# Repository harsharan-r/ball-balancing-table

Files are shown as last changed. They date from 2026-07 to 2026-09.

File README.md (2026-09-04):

# Ball Balancing Table 

A small deskstop ping pong ball balancing machine that uses a Pi Camera Module 3 to track the ping pong ball, and uses three MG 996R on a 3 DOF Stewart type platform. Everything is done via Raspberry Pi 3B+ 1 GB ram with a adafruit servo hat. The goal was to explore computer vision, state estimation, and motion controls. 

## Demo

## About this project

Three servo-actuated legs drive an RRS parallel linkage under a 120mm platform. A Pi Camera
tracks the ball's position via HSV color masking, a Kalman filter smooths that into a
position + velocity estimate, and independent PID loops on roll/pitch/height keep the ball
centered.

## Getting Started

### Prerequisites

- Raspberry Pi (tested on a Pi 3B+) running Raspberry Pi OS, with a Pi Camera Module and an
  Adafruit PCA9685 servo hat wired over I2C
- `cmake` >= 3.16, a C++17 compiler
- System packages: `opencv4`, `libcamera`, `yaml-cpp`, `pigpio`, `wiringPi`

### Installation

```
./balance setup   # installs system packages, enables I2C, configures the CMake build dir
./balance build   # cmake --build build
```

### Usage

```
./balance run
```

Runs `sudo ./build/main`, since GPIO/I2C access requires root. Use the two GPIO buttons to
move between idle / ready / calibration / running states (see `CLAUDE.md` for details).

`./balance` is a thin wrapper around `scripts/setup.sh`, `scripts/build.sh`, and
`scripts/run.sh`, which can also be run directly.

## Implementation Details

### Camera Pipeline

The camera pipeline uses libcamera to get images from pi camera module 3.

Each libcamera frame buffer is `mmap`'d directly into a `cv::Mat` header — zero copy, no
`.clone()` needed. From there the pipeline is ordered to shrink the image as early as
possible, before any of the more expensive per-pixel work runs:

1. **Crop to ROI, then downsample** — a plain `cv::Mat` sub-view followed
   by `cv::resize`. The image is first cropped to only cover the area of the platform, then resized to reduce its quality to a point where there are enough pixels (10+) to define the ping pong ball at a 50 cm distance. Cropping/resizing first means every later stage runs on a much smaller
   image instead of the full sensor resolution.
2. **BGRA → BGR → HSV** color conversion on the now-small frame.

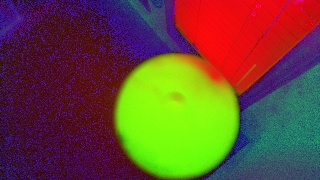
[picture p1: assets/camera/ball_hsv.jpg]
HSV frame
   
3. **`cv::inRange`** thresholds against the calibrated HSV range, then `cv::erode` +
   `cv::dilate` clean up the mask in place, reusing the same buffer rather than allocating
   a new one each step.

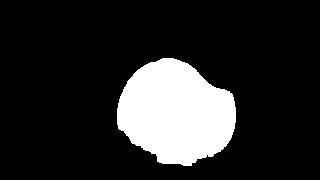
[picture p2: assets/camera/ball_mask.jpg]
Thresholded mask
   
4. **Contour detection** finds the largest contour in the mask and fits a minimum enclosing
   circle to get the ball's center and radius.

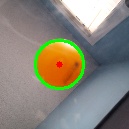
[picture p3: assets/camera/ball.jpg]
Detected ball
   

Doing the crop/resize *before* the color conversion and masking is the main optimization:
it's much cheaper to shrink one BGRA frame than to run HSV conversion, thresholding, and
morphology at full sensor resolution and shrink the result afterward.

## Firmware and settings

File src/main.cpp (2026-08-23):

#include "main.h"
#include "main_config.h"
#include <atomic>
#include <chrono>
#include <iostream>
#include <thread>
#include <memory>
#include <pigpio.h>
#include <yaml-cpp/yaml.h>

std::atomic<bool> keepRunning(true);

void setup_gpio(const MainConfig& cfg){
    gpioSetMode(cfg.led_red_gpio_pin, PI_OUTPUT);
    gpioSetMode(cfg.led_blue_gpio_pin, PI_OUTPUT);
    gpioSetMode(cfg.led_green_gpio_pin, PI_OUTPUT);
    gpioSetMode(cfg.button_left_gpio_pin, PI_INPUT);
    gpioSetMode(cfg.button_right_gpio_pin, PI_INPUT);

    gpioSetPullUpDown(cfg.button_left_gpio_pin, PI_PUD_UP);
    gpioSetPullUpDown(cfg.button_right_gpio_pin, PI_PUD_UP);

    gpioWrite(cfg.led_red_gpio_pin, PI_LOW);
    gpioWrite(cfg.led_blue_gpio_pin, PI_LOW);
    gpioWrite(cfg.led_green_gpio_pin, PI_LOW);
}

void set_led_colour(const MainConfig& cfg, int red, int green, int blue){
    gpioPWM(cfg.led_red_gpio_pin, red);
    gpioPWM(cfg.led_blue_gpio_pin, blue);
    gpioPWM(cfg.led_green_gpio_pin, green);
}

void cleanup_gpio(const MainConfig& cfg){
    gpioPWM(cfg.led_red_gpio_pin, 0);
    gpioPWM(cfg.led_blue_gpio_pin, 0);
    gpioPWM(cfg.led_green_gpio_pin, 0);

    // This stops the internal pigpio PWM peripheral threads safely.
    gpioSetMode(cfg.led_red_gpio_pin, PI_INPUT);
    gpioSetMode(cfg.led_blue_gpio_pin, PI_INPUT);
    gpioSetMode(cfg.led_green_gpio_pin, PI_INPUT);
}

void signalHandler(int signum) {
    keepRunning = false;
}

int main(){

    // CONFIG SETUP
    MainConfig cfg(YAML::LoadFile(APP_CONFIG_PATH)["main"]);

    // GPIO SETUP
    if (gpioInitialise() < 0) {
        std::cerr << "pigpio initialization failed." << std::endl;
        gpioTerminate();
        return 1;
    }
    std::cout << "pigpio initialized successfully." << std::endl;

    gpioSetSignalFunc(2, signalHandler);
    setup_gpio(cfg);

    // SERVO SETUP
    PCA9685 hat(cfg.pca9685_addr, cfg.pca9685_freq);
    Servo servo_center(hat, cfg.servo_center_channel, cfg.servo_center_min_pulse_us, cfg.servo_center_max_pulse_us);
    Servo servo_left  (hat, cfg.servo_left_channel,   cfg.servo_left_min_pulse_us,   cfg.servo_left_max_pulse_us);
    Servo servo_right (hat, cfg.servo_right_channel,  cfg.servo_right_min_pulse_us,  cfg.servo_right_max_pulse_us);

    // SHARED VALUES SETUP
    auto ball_x = std::make_shared<double>(0.0);
    auto ball_y = std::make_shared<double>(0.0);
    auto ball_radius = std::make_shared<double>(0.0);
    auto ball_stale_ = std::make_shared<bool>(true);
    auto ball_capture_frame_ = std::make_shared<int>(-1);
    std::shared_mutex ball_mtx_;

    // HELPER OBJECTS
    BallTracker ball_tracker(APP_CONFIG_PATH, ball_x, ball_y, ball_radius, ball_stale_, ball_mtx_, ball_capture_frame_);
    BalanceController balance_controller(APP_CONFIG_PATH, servo_center, servo_left, servo_right, ball_x, ball_y, ball_radius, ball_stale_, ball_mtx_, ball_capture_frame_);

    // STATE VARIABLES
    bool button_left_released = true;
    bool button_right_released = true;

    std::string state = "ready";

    std::chrono::milliseconds delay(cfg.main_loop_delay_ms);

    while(keepRunning){

        if(state == "idle"){
            set_led_colour(cfg, 250,35,0);

            balance_controller.idle();

            // Transition to ready state
            if(gpioRead(cfg.button_left_gpio_pin) == 0 && button_left_released) {
                // ==================== TEMP TUNING INSTRUMENTATION ====================
                balance_controller.reload_config();
                // =======================================================================
                state = "ready";
            }
        }
        else if(state == "ready"){
            set_led_colour(cfg, 0,0,255);

            balance_controller.ready();

            // Transition to idle state
            if(gpioRead(cfg.button_left_gpio_pin) == 0 && gpioRead(cfg.button_right_gpio_pin) == 0) {
                state = "idle";
            }
            // Transition to running state
            else if(gpioRead(cfg.button_left_gpio_pin) == 0 && button_left_released){
                ball_tracker.startTracking();
                balance_controller.start_balancing_thread();
                set_led_colour(cfg, 150,150,15);
                state = "running";
            }
            // Transition to calibration state
            else if(gpioRead(cfg.button_right_gpio_pin) == 0 && button_right_released){
                ball_tracker.startCalibration();
                state = "calibration";
            }
        }
        else if(state == "running"){

            // balance_controller.running();

            // Transition to ready state
            if(gpioRead(cfg.button_left_gpio_pin) == 0 && button_left_released){
                ball_tracker.stopCamera();
                balance_controller.stop_balancing_thread();
                // ==================== TEMP TUNING INSTRUMENTATION ====================
                balance_controller.plot_and_clear_log();
                balance_controller.reload_config();
                // =======================================================================
                state = "ready";
            }
        }
        else if(state == "calibration"){
            set_led_colour(cfg, 100,0,180);
            std::shared_lock<std::shared_mutex> lock(ball_mtx_);
            // Transition to ready state
            if(ball_tracker.is_calibrated) {
                ball_tracker.stopCamera();
                // ==================== TEMP TUNING INSTRUMENTATION ====================
                balance_controller.reload_config();
                // =======================================================================
                state = "ready";
            }
        }

        if(gpioRead(cfg.button_left_gpio_pin) == 0 && button_left_released) button_left_released = false;
        else if(gpioRead(cfg.button_left_gpio_pin) == 1 && !button_left_released) button_left_released = true;

        if(gpioRead(cfg.button_right_gpio_pin) == 0 && button_right_released) button_right_released = false;
        else if(gpioRead(cfg.button_right_gpio_pin) == 1 && !button_right_released) button_right_released = true;

        std::this_thread::sleep_for(delay);
    }

    ball_tracker.shutdown();
    cleanup_gpio(cfg);
    gpioTerminate();

    return 0;
}

//compile
// mkdir -p build &&  g++ -std=c++17 main.cpp ./perception/ball_tracker/ball_tracker.cpp ./action/servo/servo.cpp ./control/balance_controller/balance_controller.cpp ./control/pid_controller/pid_controller.cpp -o build/main `pkg-config --cflags --libs opencv4 libcamera` -lyaml-cpp -lpigpio -lwiringPi
// g++ -Wall -pthread -o pigpio_blink main.cpp -lpigpio -lyaml-cpp
// g++ servo.cpp -o servo -lwiringPi

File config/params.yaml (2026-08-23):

main:
  # GPIO pins
  BUTTON_LEFT_GPIO_PIN: 21
  BUTTON_RIGHT_GPIO_PIN: 19
  LED_RED_GPIO_PIN: 12
  LED_BLUE_GPIO_PIN: 16
  LED_GREEN_GPIO_PIN: 13

  # PCA9685 / servo channels
  PCA9685_ADDR: 0x40
  PCA9685_FREQ: 50
  SERVO_CENTER_CHANNEL: 11
  SERVO_LEFT_CHANNEL: 9
  SERVO_RIGHT_CHANNEL: 10

  # Servo pulse width calibration, in microseconds (0 deg / 180 deg)
  SERVO_CENTER_MIN_PULSE_US: 500
  SERVO_CENTER_MAX_PULSE_US: 2700
  SERVO_LEFT_MIN_PULSE_US: 500
  SERVO_LEFT_MAX_PULSE_US: 2700
  SERVO_RIGHT_MIN_PULSE_US: 500
  SERVO_RIGHT_MAX_PULSE_US: 2700

  # Main loop
  MAIN_LOOP_DELAY_MS: 100

control:
  balance_controller:
    # Platform known values
    ARM_DIST_FROM_CENTER: 55
    ARM_TO_ARM_DIST: 95

    # Servo arm known values
    AXIS_OFFSET: 30.0
    LOWER_ARM_LENGTH: 45.0
    UPPER_ARM_LENGTH: 98.0

    # Servo offset so lower arm point up is defined as 0 degs
    SERVO_CENTER_REFERENCE_OFFSET: 34
    SERVO_LEFT_REFERENCE_OFFSET: 45.0
    SERVO_RIGHT_REFERENCE_OFFSET: 39.0

    # Servo idle mode angles in mm
    SERVO_CENTER_IDLE_HEIGHT: 75.0 # 65 # TODO change back
    SERVO_LEFT_IDLE_HEIGHT: 75.0  # 68
    SERVO_RIGHT_IDLE_HEIGHT: 75.0 #68

    # Platform ready mode values in mm
    PLATFORM_READY_HEIGHT: 115.0
    PLATFORM_READY_ROLL: 0.0
    PLATFORM_READY_PITCH: 0.0

    # Runner thread 
    BALANCE_CONTROLLER_THREAD_DELAY_MS: 10

    # Kalman filter values (1D constant-velocity, one filter per axis)
    # process noise = how much we trust the constant-velocity model between frames
    # measurement noise = how noisy the raw camera-derived position reading is
    # starting points only -- tune per-axis on hardware
    KALMAN_X_PROCESS_NOISE_POS: 0.00001 # 0.01
    KALMAN_X_PROCESS_NOISE_VEL: 0.2  # 0.5
    KALMAN_X_MEASUREMENT_NOISE: 0.00000136

    KALMAN_Y_PROCESS_NOISE_POS: 0.00001
    KALMAN_Y_PROCESS_NOISE_VEL: 0.2  #0.025
    KALMAN_Y_MEASUREMENT_NOISE: 0.00000050

    KALMAN_RADIUS_PROCESS_NOISE_POS: 0.0000001
    KALMAN_RADIUS_PROCESS_NOISE_VEL: 0.0005
    KALMAN_RADIUS_MEASUREMENT_NOISE: 0.00000003

    PID_ANTI_WINDUP: true
    PID_ANTI_WINDUP_THRESHOLD: 0.1

    # PID gains and clamp values
    PID_ROLL_KP: 7.2 #5.9 , 6.1, 6.1, 7.2
    PID_ROLL_KI: 0.0 
    PID_ROLL_KD: 3.8 #4.1 , 4.15, 3.8, 3.8
    PID_ROLL_MIN: -35.0
    PID_ROLL_MAX: 35.0

    PID_PITCH_KP: 7.85 # 7.85 
    PID_PITCH_KI: 0.0 
    PID_PITCH_KD: 4.15 # 4.15 
    PID_PITCH_MIN: -35.0
    PID_PITCH_MAX: 35.0

    PID_HEIGHT_KP: 300.0
    PID_HEIGHT_KI: 0.0
    PID_HEIGHT_KD: 0.0
    PID_HEIGHT_MIN: -5.0
    PID_HEIGHT_MAX: 15.0
    PID_HEIGHT_THRESHOLD: 0.05

    TARGET_RADIUS: 0.14
    
    PID_ROLL_DERIVATIVE_DEADBAND: 0.0 # 0.4
    PID_PITCH_DERIVATIVE_DEADBAND: 0.0 # 0.4
    PID_HEIGHT_DERIVATIVE_DEADBAND: 0.15 # 0.4

    PID_ROLL_DERIVATIVE_DEADBAND_MULTI: 1.0 # 0.4
    PID_PITCH_DERIVATIVE_DEADBAND_MULTI: 1.0 # 0.4
    PID_HEIGHT_DERIVATIVE_DEADBAND_MULTI: 1.0 # 0.4


perception:
  ball_tracker:
    # Stream Settings
    CAMERA_STREAM_INDEX: 0
    CAMERA_STREAM_INDEX: 0
    CAMERA_STREAM_WIDTH: 2304
    CAMERA_STREAM_HEIGHT: 1296
    CAMERA_FRAME_RATE: 35
    CAMERA_AE_WARMUP_FRAMES: 100
    CAMERA_AF_WARMUP_FRAMES: 120
    CAMERA_EXPOSURE_TIME: 27202
    CAMERA_ANALOGUE_GAIN: 5.78
    CAMERA_LENS_POSITION: 8.42 

    # Image Processing Settings 
    IMAGE_DOWNSAMPLING_FACTOR: 10
    IMAGE_CROP_WIDTH: 1480
    IMAGE_CROP_HEIGHT: 1296

    # Calibration Settings
    CALIBRATION_MARGIN: 2.5
    CALIBRATION_X_PX: 1152
    CALIBRATION_Y_PX: 648
    CALIBRATION_RADIUS_PX: 180
    HSV_CLAMP_HUE_MIN: 0
    HSV_CLAMP_SAT_MIN: 0
    HSV_CLAMP_VALUE_MIN: 0
    HSV_CLAMP_HUE_MAX: 179
    HSV_CLAMP_SAT_MAX: 255
    HSV_CLAMP_VALUE_MAX: 255

    # Default Ball Values Before Calibration
    BALL_SEARCH_HUE_MIN: 8
    BALL_SEARCH_HUE_MAX: 23
    BALL_SEARCH_SAT_MIN: 163
    BALL_SEARCH_SAT_MAX: 255
    BALL_SEARCH_VALUE_MIN: 183
    BALL_SEARCH_VALUE_MAX: 248

action:

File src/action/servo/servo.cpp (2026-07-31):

// servo.cpp
#include "action/servo/servo.h"
#include <wiringPiI2C.h>
#include <cmath>
#include <unistd.h>
#include <iostream>
#include <stdexcept>
#include <string>

// ── PCA9685 ──────────────────────────────────────────────
PCA9685::PCA9685(uint8_t addr, int freq) {
    fd = wiringPiI2CSetup(addr);
    if (fd < 0) {
        throw std::runtime_error("Failed to open I2C device at address 0x40");
    }

    reset();
    wiringPiI2CWriteReg8(fd, MODE2_REG, 0x04);
    setFreq(freq);
}

void PCA9685::reset() {
    wiringPiI2CWriteReg8(fd, MODE1_REG, 0x00);
    usleep(5000);
}

void PCA9685::setFreq(int freq) {
    int prescale = static_cast<int>(25000000.0f / (4096.0f * freq) + 0.5f) - 1;
    int oldMode  = wiringPiI2CReadReg8(fd, MODE1_REG);

    wiringPiI2CWriteReg8(fd, MODE1_REG,     (oldMode & 0x7F) | 0x10);
    wiringPiI2CWriteReg8(fd, PRE_SCALE_REG, prescale);
    wiringPiI2CWriteReg8(fd, MODE1_REG,     oldMode);
    usleep(5000);
    wiringPiI2CWriteReg8(fd, MODE1_REG,     oldMode | 0xA0);
}

void PCA9685::setPWM(int channel, int on, int off) {
    int base = LED0_BASE_REG + 4 * channel;
    wiringPiI2CWriteReg8(fd, base,     on  & 0xFF);
    wiringPiI2CWriteReg8(fd, base + 1, on  >> 8);
    wiringPiI2CWriteReg8(fd, base + 2, off & 0xFF);
    wiringPiI2CWriteReg8(fd, base + 3, off >> 8);
}

// ── Servo ─────────────────────────────────────────────────
Servo::Servo(PCA9685& board, int channel, int minPulse, int maxPulse)
    : brd(board),
      servo_channel(channel),
      SERVO_MIN(static_cast<int>(minPulse / US_PER_TICK)),
      SERVO_MAX(static_cast<int>(maxPulse / US_PER_TICK))
{}

int Servo::angleToPulse(float angle) {
    if (angle < MIN_ANGLE || angle > MAX_ANGLE) return -1;

    double pulse = SERVO_MIN + (angle / 180.0) * (SERVO_MAX - SERVO_MIN);
    return static_cast<int>(std::lround(pulse));
}

void Servo::setPWM(int on, int off) {
    brd.setPWM(servo_channel, on, off);
}

void Servo::setAngle(float angle) {
    int pulse = angleToPulse(angle);
    if (pulse < 0)
        std::cerr << "Angle must be between " << MIN_ANGLE << " and " << MAX_ANGLE << std::endl;
    else
        setPWM(0, pulse);
}

// int main() {
//      PCA9685 hat(0x40, 50);

//      Servo servo_left  (hat,  9);
//      Servo servo_right (hat, 10);
//      Servo servo_center(hat, 11);

//      servo_left.setAngle(170 - 33);
//      servo_right.setAngle(170 - 38);
//      servo_center.setAngle(170 - 44); //57
//      sleep(1);
//      return 0;
// }

// Compile
// g++ servo.cpp -o servo -lwiringPi

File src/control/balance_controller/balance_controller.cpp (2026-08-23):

#include "control/balance_controller/balance_controller.h"

#include <string>
#include <unordered_map>
#include <cmath>
#include <iostream>
#include <memory>
#include <shared_mutex>
#include <thread>

#include <yaml-cpp/yaml.h>

// ==================== TEMP TUNING INSTRUMENTATION ====================
#include <cstdlib>
#include <fstream>
// =======================================================================

BalanceController::BalanceController(
    const std::string& config_path,
    Servo& servo_center,
    Servo& servo_left,
    Servo& servo_right,
    std::shared_ptr<double> ball_x,
    std::shared_ptr<double> ball_y,
    std::shared_ptr<double> ball_radius,
    std::shared_ptr<bool> ball_stale,
    std::shared_mutex& ball_mtx,
    std::shared_ptr<int> ball_capture_frame
)
    : servo_center_(servo_center),
      servo_left_(servo_left),
      servo_right_(servo_right),
      ball_x_(ball_x),
      ball_y_(ball_y),
      ball_radius_(ball_radius),
      ball_stale_(ball_stale),
      ball_mtx_(ball_mtx),
      ball_capture_frame_(ball_capture_frame)
{
    // ==================== TEMP TUNING INSTRUMENTATION ====================
    config_path_ = config_path;
    // =======================================================================

    YAML::Node config = YAML::LoadFile(config_path)["control"]["balance_controller"];
    cfg_ = BalanceControllerConfig(config);

    roll_controller.setGains(cfg_.PID_roll_kp, cfg_.PID_roll_ki, cfg_.PID_roll_kd);
    roll_controller.setOutputLimits(cfg_.PID_roll_min, cfg_.PID_roll_max);
    roll_controller.setAntiWindup(cfg_.PID_anti_windup, cfg_.PID_anti_windup_threshold);

    pitch_controller.setGains(cfg_.PID_pitch_kp, cfg_.PID_pitch_ki, cfg_.PID_pitch_kd);
    pitch_controller.setOutputLimits(cfg_.PID_pitch_min, cfg_.PID_pitch_max);
    pitch_controller.setAntiWindup(cfg_.PID_anti_windup, cfg_.PID_anti_windup_threshold);

    height_controller.setGains(cfg_.PID_height_kp, cfg_.PID_height_ki, cfg_.PID_height_kd);
    height_controller.setOutputLimits(cfg_.PID_height_min, cfg_.PID_height_max);
    height_controller.setAntiWindup(cfg_.PID_anti_windup, cfg_.PID_anti_windup_threshold);

    kf_x_.setNoise(cfg_.kalman_x_process_noise_pos, cfg_.kalman_x_process_noise_vel, cfg_.kalman_x_measurement_noise);
    kf_y_.setNoise(cfg_.kalman_y_process_noise_pos, cfg_.kalman_y_process_noise_vel, cfg_.kalman_y_measurement_noise);
    kf_radius_.setNoise(cfg_.kalman_radius_process_noise_pos, cfg_.kalman_radius_process_noise_vel, cfg_.kalman_radius_measurement_noise);
}

BalanceController::~BalanceController() {
    stop_balancing_thread();
}

void BalanceController::idle(){

  float servo_center_angle = height_to_servo_angle(cfg_.servo_center_idle_height, cfg_.servo_center_reference_offset);
  float servo_left_angle = height_to_servo_angle(cfg_.servo_left_idle_height, cfg_.servo_left_reference_offset);
  float servo_right_angle = height_to_servo_angle(cfg_.servo_right_idle_height, cfg_.servo_right_reference_offset);

  servo_center_.setAngle(servo_center_angle);
  servo_left_.setAngle(servo_left_angle);
  servo_right_.setAngle(servo_right_angle);
}

void BalanceController::ready(){

    // TODO make this cleaner logic: make it all a function
  float roll = deg_to_rad(cfg_.platform_ready_roll);
  float pitch = deg_to_rad(cfg_.platform_ready_pitch);
  float height = cfg_.platform_ready_height;

  std::unordered_map<std::string, float> heights = rpz_to_arm_heights(roll, pitch, height);

  float servo_center_angle = height_to_servo_angle(heights["center_arm_height"], cfg_.servo_center_reference_offset);
  float servo_left_angle = height_to_servo_angle(heights["left_arm_height"], cfg_.servo_left_reference_offset);
  float servo_right_angle = height_to_servo_angle(heights["right_arm_height"], cfg_.servo_right_reference_offset);

  servo_center_.setAngle(servo_center_angle);
  servo_left_.setAngle(servo_left_angle);
  servo_right_.setAngle(servo_right_angle);
}

void BalanceController::start_balancing_thread(){
    if (runner_thread && runner_thread->joinable()) {
        return;
    }

    stop_flag.store(false);

    runner_thread = std::make_unique<std::thread>(&BalanceController::running, this);
}

void BalanceController::stop_balancing_thread(){
    if (runner_thread && runner_thread->joinable()) {
        stop_flag.store(true);
        
        runner_thread->join();
        runner_thread.reset(); 
    }
}

// ==================== TEMP TUNING INSTRUMENTATION ====================
void BalanceController::reload_config(){
    YAML::Node config = YAML::LoadFile(config_path_)["control"]["balance_controller"];
    cfg_ = BalanceControllerConfig(config);

    roll_controller.setGains(cfg_.PID_roll_kp, cfg_.PID_roll_ki, cfg_.PID_roll_kd);
    roll_controller.setOutputLimits(cfg_.PID_roll_min, cfg_.PID_roll_max);
    roll_controller.setAntiWindup(cfg_.PID_anti_windup, cfg_.PID_anti_windup_threshold);

    pitch_controller.setGains(cfg_.PID_pitch_kp, cfg_.PID_pitch_ki, cfg_.PID_pitch_kd);
    pitch_controller.setOutputLimits(cfg_.PID_pitch_min, cfg_.PID_pitch_max);
    pitch_controller.setAntiWindup(cfg_.PID_anti_windup, cfg_.PID_anti_windup_threshold);

    height_controller.setGains(cfg_.PID_height_kp, cfg_.PID_height_ki, cfg_.PID_height_kd);
    height_controller.setOutputLimits(cfg_.PID_height_min, cfg_.PID_height_max);
    height_controller.setAntiWindup(cfg_.PID_anti_windup, cfg_.PID_anti_windup_threshold);

    kf_x_.setNoise(cfg_.kalman_x_process_noise_pos, cfg_.kalman_x_process_noise_vel, cfg_.kalman_x_measurement_noise);
    kf_y_.setNoise(cfg_.kalman_y_process_noise_pos, cfg_.kalman_y_process_noise_vel, cfg_.kalman_y_measurement_noise);
    kf_radius_.setNoise(cfg_.kalman_radius_process_noise_pos, cfg_.kalman_radius_process_noise_vel, cfg_.kalman_radius_measurement_noise);

    std::cout << "[tuning] config reloaded from " << config_path_ << std::endl;
}

void BalanceController::plot_and_clear_log(){
    const std::string log_path = "/home/harsh/Documents/Projects/ball-balancing-table/.logs/tuning_xy.txt";
    const std::string script_path = "/home/harsh/Documents/Projects/ball-balancing-table/scripts/plot_tuning.py";

    int result = std::system(("python3 " + script_path + " " + log_path).c_str());
    if (result != 0) {
        std::cerr << "[tuning] plot_tuning.py failed (exit code " << result << ")" << std::endl;
    }

    std::ofstream clear_log(log_path, std::ios::trunc);
}
// =======================================================================
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

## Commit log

2026-06-24 added servo base class
2026-06-25 added ball tracker class to replace camera file
2026-06-28 Added class for tracking ball with pi camera module 3
2026-07-01 added conversions for main inputs to servo angles
2026-07-31 added predicition between frames
2026-07-31 added pid controller object
2026-08-22 added af to calibration and fixed bug of new control settings geting overwritten
2026-08-22 added kalman filter
2026-09-04 Added camera pipeline
2026-09-04 added camera pipeline images
2026-09-10 added inverse kinematics math
2026-09-10 added stl files
    [Base.STL, RPI_hat_standoffs.STL, ball_joint.STL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]
2026-09-10 Added state machine and inverse kinematics
2026-09-10 Added kalman and pid to readme
